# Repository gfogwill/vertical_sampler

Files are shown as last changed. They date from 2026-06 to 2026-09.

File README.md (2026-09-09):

# Vertical Sampler

Firmware, hardware and host software for a balloon-borne vertical air sampler for Ice Nucleating Particle (INP) collection.

Payload and ground-station Raspberry Pi Pico W boards run **CircuitPython** and communicate over **LoRa at 868 MHz**. The system supports two payload identities: `kenttarova` and `matorova`.

## System Overview

```text
┌─────────────────────────┐        LoRa 868 MHz         ┌─────────────────────────┐
│        PAYLOAD          │◄───────────────────────────►│    GROUND STATION       │
│  Raspberry Pi Pico W    │                             │  Raspberry Pi Pico W    │
│                         │                             │                         │
│  - GPS (+ RTC sync)     │                             │  - Receives telemetry   │
│  - SHT85 RH/temp sensor │                             │  - Relays to PC via USB │
│  - LPS25H pressure      │                             │  - Forwards commands    │
│  - Pumps + electrovalve │                             └─────────────────────────┘
│  - SD logging           │                                         │
│  - Battery + flow meter │                                    USB Serial
│  - Watchdog             │                                         │
└─────────────────────────┘                             ┌─────────────────────────┐
                                                        │       Host computer     │
                                                        │ host/cli.py             │
                                                        │ host/quickview.py       │
                                                        └─────────────────────────┘
```

## Repository Structure

```text
vertical_sampler/
├── firmware/                    # CircuitPython code deployed to Pico boards
│   ├── common/                  # Copied flat to every CIRCUITPY drive
│   │   ├── config.py            # PCB v1 GPIOs, calibration, limits, LoRa addresses
│   │   ├── payload.py           # Active payload drivers and mission loop
│   │   ├── lora.py              # RFM9x wrapper
│   │   ├── pressure_sensor.py   # LPS25H driver
│   │   ├── sdcard.py            # SD mount, JSONL data and log writes
│   │   ├── logging.py
│   │   ├── pack.py              # Binary LoRa telemetry format
│   │   ├── led.py
│   │   ├── adafruit_gps.py      # Vendored CircuitPython dependency
│   │   └── adafruit_rfm9x.py    # Vendored CircuitPython dependency
│   ├── kenttarova_main.py       # kenttarova payload entry point
│   ├── matorova_main.py         # matorova payload entry point
│   └── ground_main.py           # Ground-station entry point
├── host/                        # Python 3 programs running on the control PC
│   ├── cli.py
│   └── quickview.py
├── pcb/                         # KiCad PCB v1 project
├── docs/
│   └── TROUBLESHOOTING.md
├── Makefile
└── README.md
```

`firmware/common/` is copied as flat modules to the root of `CIRCUITPY`. CircuitPython imports therefore remain simple:

```python
import config
import lora
import pack
```

## Payload Identities

| Unit | LoRa node address | Entry point |
|---|---:|---|
| Ground station | `0x47` | `firmware/ground_main.py` |
| kenttarova | `0x71` | `firmware/kenttarova_main.py` |
| matorova | `0x93` | `firmware/matorova_main.py` |

Addresses, GPIO assignments, calibration constants and safety limits are defined centrally in `firmware/common/config.py`.

## Quick Start

### 1. Flash CircuitPython

```bash
make download-circuitpython-image
```

Copy the resulting `.uf2` to the Pico W while it is in BOOTSEL mode.

### 2. Install dependencies

The repository vendors `adafruit_gps.py` and `adafruit_rfm9x.py`. Install the remaining required CircuitPython libraries in the Pico `lib/` directory, including the dependencies required by the RFM9x driver such as `adafruit_bus_device`.

### 3. Deploy firmware

Set the CircuitPython mount point if needed:

```bash
export CIRCUITPY_PATH=/media/$USER/CIRCUITPY
```

Deploy the required device image:

```bash
make update-kenttarova
make update-matorova
make update-ground
```

Each target:

1. Removes stale `code.py`.
2. Copies all `firmware/common/*.py` modules to the Pico.
3. Copies the selected entry point as `main.py`.

### 4. Control a payload

Run commands from the host computer:

```bash
python host/cli.py kenttarova data
python host/cli.py kenttarova pump front on
python host/cli.py kenttarova pump back off
python host/cli.py kenttarova valve on
python host/cli.py matorova data
```

`host/quickview.py` is available for local data inspection and visualization.

The host dashboards automatically use the latest sea-level pressure observation
from FMI station `Kittilä Matorova` (`fmisid=101985`) as QNH. The value is
refreshed every 10 minutes through the public
[FMI WFS API](https://opendata.fmi.fi/wfs). If FMI is unavailable, the last
fresh FMI value is retained and then the manual/default value of 1013.25 hPa
is used. Pass `--qnh VALUE` to select a different fallback, or
`--no-auto-qnh` to disable automatic updates. Logged monitor samples include
`_qnh_hpa`, `_qnh_source` and `_qnh_observation_time` so derived altitude
remains traceable.

## Telemetry Format

Each payload sample is logged as JSONL when an SD card is available and sent over LoRa as a packed binary packet defined in `firmware/common/pack.py`.

| Field | Type | Description |
|---|---|---|
| `msg_type` | str | `telemetry`, `cmd_ack` or `cmd_err` |
| `payload_id` | str | `kenttarova` or `matorova` |
| `rtc_time` | str | RTC timestamp in ISO 8601 format |
| `gps_time` | uint32/null | GPS UTC Unix epoch |
| `gps_latitude` | float/null | Degrees |
| `gps_longitude` | float/null | Degrees |
| `gps_altitude` | float/null | Metres |
| `rh_sensor_humidity` | float | Relative humidity, % |
| `rh_sensor_temperature` | float | Temperature, °C |
| `pressure_sensor_pressure` | float | Pressure, mbar |
| `pressure_sensor_temperature` | float | Temperature, °C |
| `battery_voltage` | float | Calibrated 6S battery voltage |
| `cpu_temperature` | float | Pico internal temperature, °C |
| `flow` | float | Standard L/min |
| `rssi` | int | Last received LoRa RSSI |
| `pump_front_state` | int | 0 or 1 |
| `pump_back_state` | int | 0 or 1 |
| `valve_state` | int | 0 or 1 |

> **RTC synchronization:** on the first valid GPS fix, the payload sets the onboard RTC to GPS UTC. Subsequent `rtc_time` values remain valid even if the GPS temporarily loses its fix.

## SD Logging

The SD-card handler writes:

| File | Content |
|---|---|
| `/sd/<payload_id>_log.txt` | Human-readable events and diagnostics |
| `/sd/<payload_id>_NNN.jsonl` | One JSON object per sample cycle |

If the SD card is unavailable or fails while operating, the payload continues running and transmitting telemetry over LoRa. Logging degrades to the serial console instead of stopping the mission.

## Safety Features

| Condition | Threshold | Action |
|---|---:|---|
| Battery warning | ≤ 19.8 V | Warning logged |
| Battery critical | ≤ 18.6 V | Pumps off, valve off, error logged |
| CPU temperature warning | ≥ 45 °C | Warning logged |
| CPU temperature critical | ≥ 55 °C | Pumps off, valve off, error logged |
| Main-loop stall | 30 s watchdog timeout | Pico reset |

The watchdog is fed in the main loop, GPS wait loop, LoRa receive loop and failure-report loops.

## PCB v1 Pin Map

| Function | Pico GPIO |
|---|---:|
| GPS UART TX/RX | GP0 / GP1 |
| I2C SDA/SCL | GP2 / GP3 |
| Pump front | GP6 |
| Electrovalve | GP7 |
| SD chip select | GP9 |
| SPI SCK/MOSI/MISO | GP10 / GP11 / GP12 |
| LoRa chip select | GP16 |
| OPC chip select (reserved) | GP17 |
| Pump back | GP21 |
| Battery monitor ADC | GP27 |
| Flowmeter ADC | GP28 |

The RFM9x reset line is not routed on PCB v1. `config.LORA_RESET_DUMMY` remains because the CircuitPython RFM9x driver requires a reset-pin argument.

## Calibration

### Flowmeter

The TSI 4121 flowmeter is configured as:

- Signal range: 0–4 V corresponding to 0–20 Std L/min.
- ADC divider: 10 kΩ series resistor and 32.6 kΩ to ground.
- Divider ratio: \(32.6 / (10.0 + 32.6)\).
- Zero offset: `FLOW_OFFSET_LMIN` in `firmware/common/config.py`.

### Battery monitor

`BATTERY_CAL_FACTOR` in `firmware/common/config.py` converts the Pico ADC voltage to the measured 6S battery voltage. Recalibrate against a multimeter if the divider or analog front-end changes.

## Development Notes

- `firmware/common/payload.py` contains the active, hardware-validated payload drivers and mission loop.
- `firmware/common/config.py` is the single source of truth for PCB pins, calibration, operating limits and LoRa addresses.
- The old breadboard firmware is preserved in the `old_hardware` branch.
- See `docs/TROUBLESHOOTING.md` for deployment and communication diagnostics.

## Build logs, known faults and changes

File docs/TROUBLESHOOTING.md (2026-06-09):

# Troubleshooting

## SD Card not mounting at boot

**Symptom:** `os.listdir("/sd")` raises `OSError: [Errno 2] No such file/directory` after reset, but works fine when `SDCard(spi, ...)` is called manually in the REPL.

**Cause:** `SDCard(...)` is not being called during the boot sequence — either `main()` is not running, or an exception is thrown before the SD mount.

**Fix:** Ensure `main.py` calls `SDCard(spi, fname="log.txt")` at the start of `main()`, before creating the logger. Verify:
```python
import os
print(os.listdir("/"))   # should include 'sd'
print(os.listdir("/sd")) # should include 'log.txt'
```

---

## Payload keeps resetting / autoreload loop

**Symptom:** The payload restarts every time a file is saved to `CIRCUITPY`, or seems to restart randomly during development.

**Cause:** CircuitPython's autoreload is enabled by default. Saving any file to the drive triggers a soft reset.

**Fix:** Add this at the very top of `main.py`, **before any other imports**:
```python
import supervisor
supervisor.runtime.autoreload = False
```

---

## LoRa not initializing / SPI conflict

**Symptom:** `LoRa(...)` raises an exception, or the payload hangs on LoRa init.

**Cause:** LoRa and the SD card share the same SPI bus (GP2/GP3/GP4). SPI bus contention can occur if initialization order is wrong.

**Fix:** Always initialize `SDCard` before `LoRa` in `main()`.

---

## GPS not acquiring fix

**Symptom:** Logger shows `Waiting for GPS fix...` repeatedly.

**Fix:**
- Allow more time outdoors with a clear sky view (cold start can take 1–2 minutes).
- Increase `max_attempts` and `timeout` in `GPS.lat_lon_alt_time()`.
- Check UART wiring (GP0/GP1) and baud rate (9600).

---

## `log.txt` grows indefinitely

**Behavior (expected):** `log.txt` uses append mode and accumulates across all boots. This is intentional for flight data recovery.

**To clear the log:**
```python
import os
os.remove("/sd/log.txt")
```

---

## Payload boots but `/sd` does not appear

**Verify** the SD card is physically inserted and CS pin is GP18.

**Test manually in REPL:**
```python
import board, busio
from sdcard import SDCard
spi = busio.SPI(board.GP2, MOSI=board.GP3, MISO=board.GP4)
sd = SDCard(spi, "log.txt")
import os
print(os.listdir("/sd"))
```
If this works but boot does not, the problem is in `main.py` initialization order.

---

## `cli.py` can't find the serial port

**Fix:** Make sure the ground station Pico W is connected via USB. On Linux:
```bash
sudo usermod -a -G dialout $USER
# then log out and back in
```

---

## `cp: error writing ... No space left on device` after flashing UF2

**Symptom:** `make update-*` fails with:
```
cp: error writing '/media/.../CIRCUITPY/adafruit_gps.py': No space left on device
```
This happens even immediately after flashing a fresh UF2.

**Cause:** CircuitPython's `CIRCUITPY` drive has a fixed filesystem size baked into the UF2. By default it is **~1 MB**, which fills up quickly with libraries. Flashing the UF2 again does **not** wipe or resize the filesystem — it only replaces the firmware, leaving the old filesystem intact.

**Fix — wipe and resize the filesystem:**

1. **Enter bootloader mode:** hold BOOTSEL while plugging in USB (or double-tap RESET). The drive `RPI-RP2` appears.

2. **Flash the CircuitPython UF2** (if not already done): drag the `.uf2` onto `RPI-RP2`.

3. **Wipe the filesystem from the REPL.** Connect via serial (Thonny or `screen /dev/ttyACM0 115200`) and run:
   ```python
   import storage
   storage.erase_filesystem()
   ```
   The board will reboot and format a **fresh, empty** `CIRCUITPY` filesystem.

4. **Run `make update-*` again.** The drive is now empty and should have enough space.

**Prevention:** If the drive keeps filling up, remove unused `.py` or `.mpy` files. Pre-compiled `.mpy` files (from the Adafruit CircuitPython Bundle) are significantly smaller than `.py` sources — use them for large libraries like `adafruit_gps`.

**Check available space from REPL:**
```python
import os
s = os.statvfs("/")
free_kb = s[0] * s[3] / 1024
print("Free:", free_kb, "KB")
```

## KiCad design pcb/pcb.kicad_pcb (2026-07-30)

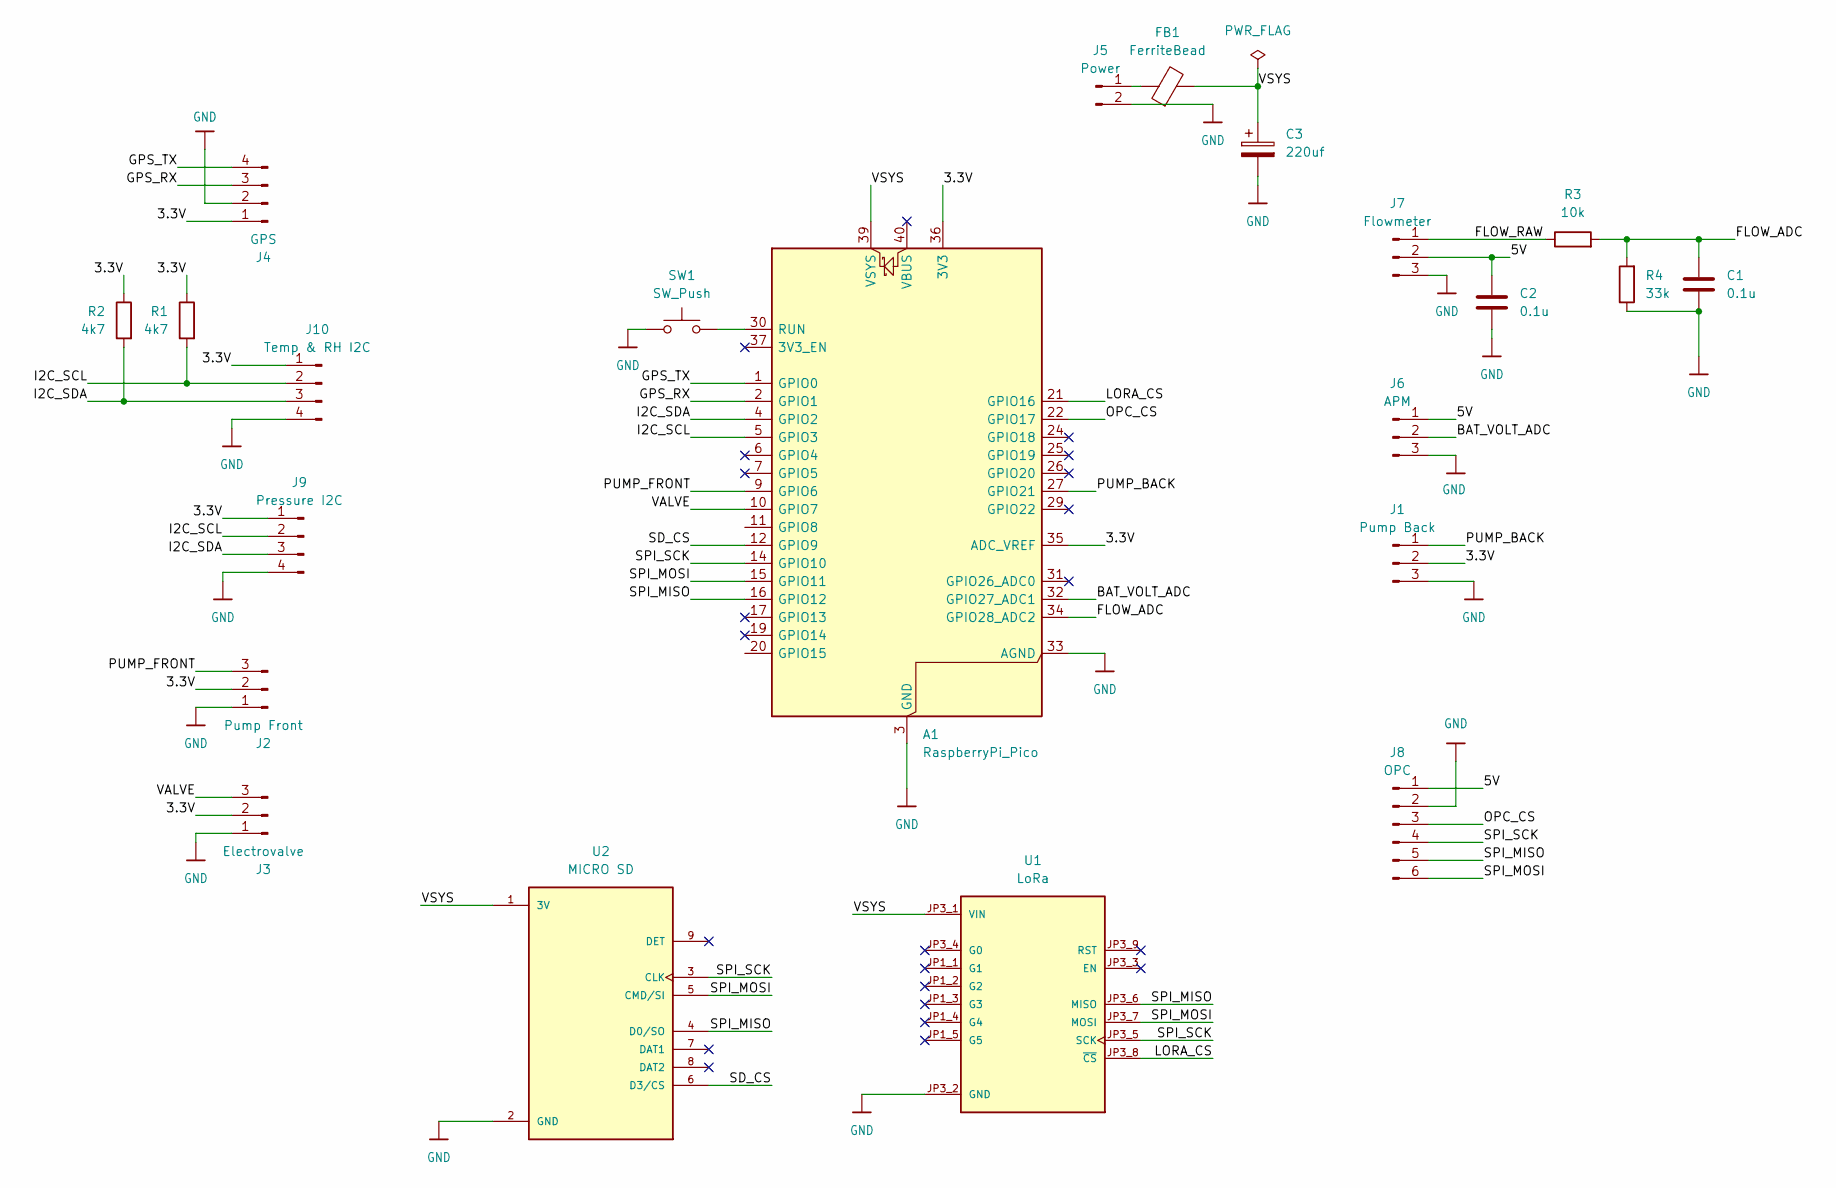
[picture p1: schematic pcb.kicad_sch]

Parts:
A1: RaspberryPi_Pico; RaspberryPi_Pico_Common_THT
C1, C2: 0.1u; C_1206_3216Metric
C3: 220uf; CP_Radial_D6.3mm_P2.50mm
FB1: FerriteBead; L_1206_3216Metric
J1: Pump Back; JST_XH_B3B-XH-A_1x03_P2.50mm_Vertical
J2: Pump Front; JST_XH_B3B-XH-A_1x03_P2.50mm_Vertical
J3: Electrovalve; JST_XH_B3B-XH-A_1x03_P2.50mm_Vertical
J4: GPS; JST_XH_B4B-XH-A_1x04_P2.50mm_Vertical
J5: Power; JST_XH_B2B-XH-A_1x02_P2.50mm_Vertical
J6: APM; JST_XH_B3B-XH-A_1x03_P2.50mm_Vertical
J7: Flowmeter; JST_XH_B3B-XH-A_1x03_P2.50mm_Vertical
J8: OPC; JST_XH_B6B-XH-A_1x06_P2.50mm_Vertical
J9: Pressure I2C; JST_XH_B4B-XH-A_1x04_P2.50mm_Vertical
J10: Temp & RH I2C; JST_XH_B4B-XH-A_1x04_P2.50mm_Vertical
R1, R2: 4k7; R_1206_3216Metric
R3: 10k; R_1206_3216Metric
R4: 33k; R_1206_3216Metric
SW1: SW_Push; SW_PUSH_6mm
U1: LoRa; MODULE_3073; PARTREV 2023-10-24
U2: MICRO SD; MODULE_MICROSD_SPI_OR_SDIO_CARD; PARTREV B

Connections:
/3.3V: A1.35 (ADC_VREF), A1.36 (3V3), J1.2, J2.2, J3.2, J4.1, J9.1, J10.1, R1.1, R2.1
/5V: C2.1, J6.1, J7.2, J8.1
/BAT_VOLT_ADC: A1.32 (GPIO27_ADC1), J6.2
/FLOW_ADC: A1.34 (GPIO28_ADC2), C1.1, R3.2, R4.2
/FLOW_RAW: J7.1, R3.1
/GPS_RX: A1.2 (GPIO1), J4.3
/GPS_TX: A1.1 (GPIO0), J4.4
/I2C_SCL: A1.5 (GPIO3), J9.2, J10.2, R1.2
/I2C_SDA: A1.4 (GPIO2), J9.3, J10.3, R2.2
/LORA_CS: A1.21 (GPIO16), U1.JP3_8 (~CS)
/OPC_CS: A1.22 (GPIO17), J8.3
/PUMP_BACK: A1.27 (GPIO21), J1.1
/PUMP_FRONT: A1.9 (GPIO6), J2.3
/SD_CS: A1.12 (GPIO9), U2.6 (D3/CS)
/SPI_MISO: A1.16 (GPIO12), J8.5, U1.JP3_6 (MISO), U2.4 (D0/SO)
/SPI_MOSI: A1.15 (GPIO11), J8.6, U1.JP3_7 (MOSI), U2.5 (CMD/SI)
/SPI_SCK: A1.14 (GPIO10), J8.4, U1.JP3_5 (SCK), U2.3 (CLK)
/VALVE: A1.10 (GPIO7), J3.3
/VSYS: A1.39 (VSYS), C3.1, FB1.2, U1.JP3_1 (VIN), U2.1 (3V)
GND: A1.3 (GND), A1.8 (GND), A1.13 (GND), A1.18 (GND), A1.23 (GND), A1.28 (GND), A1.33 (AGND), A1.38 (GND), C1.2, C2.2, C3.2, J1.3, J2.1, J3.1, J4.2, J5.2, J6.3, J7.3, J8.2, J9.4, J10.4, R4.1, SW1.1, U1.JP3_2 (GND), U2.2 (GND)
unnamed: A1.30 (RUN), SW1.2
unnamed: FB1.1, J5.1

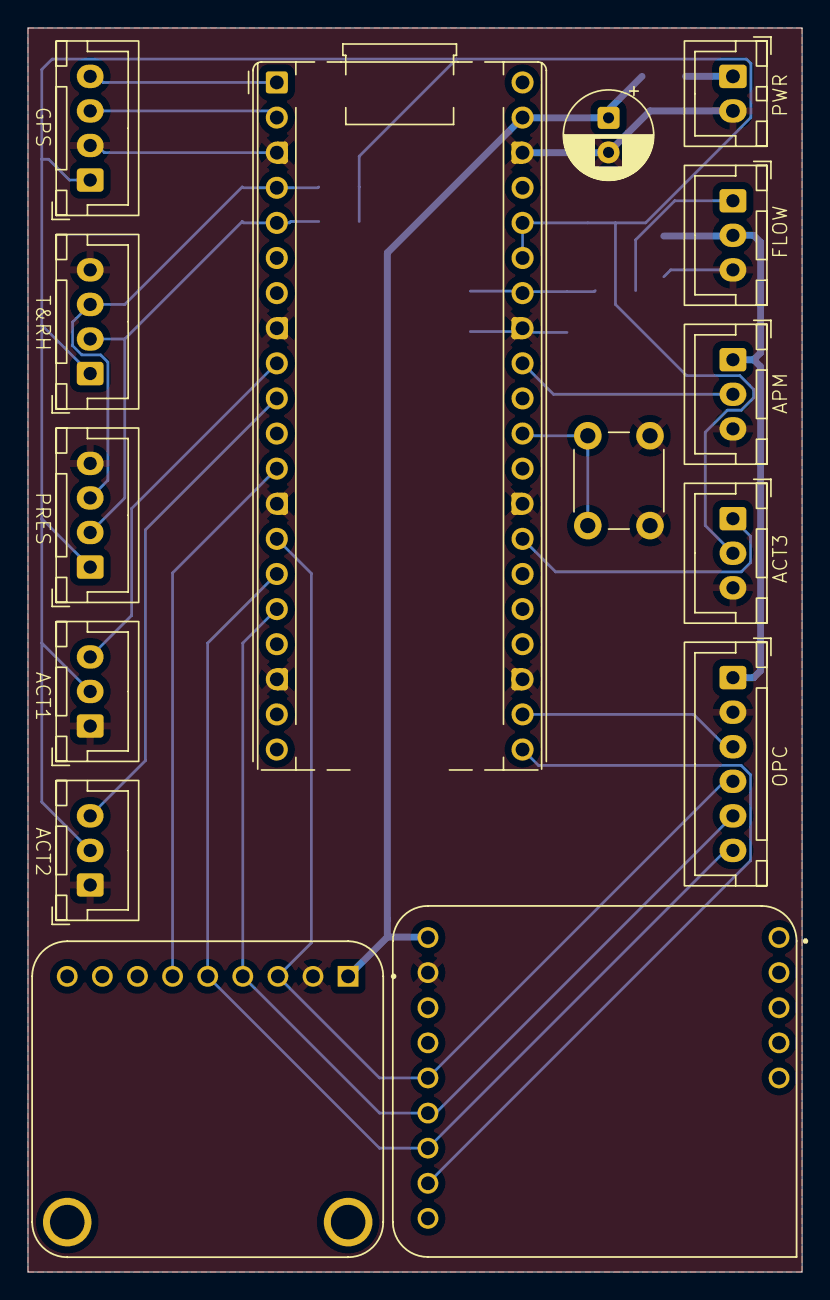
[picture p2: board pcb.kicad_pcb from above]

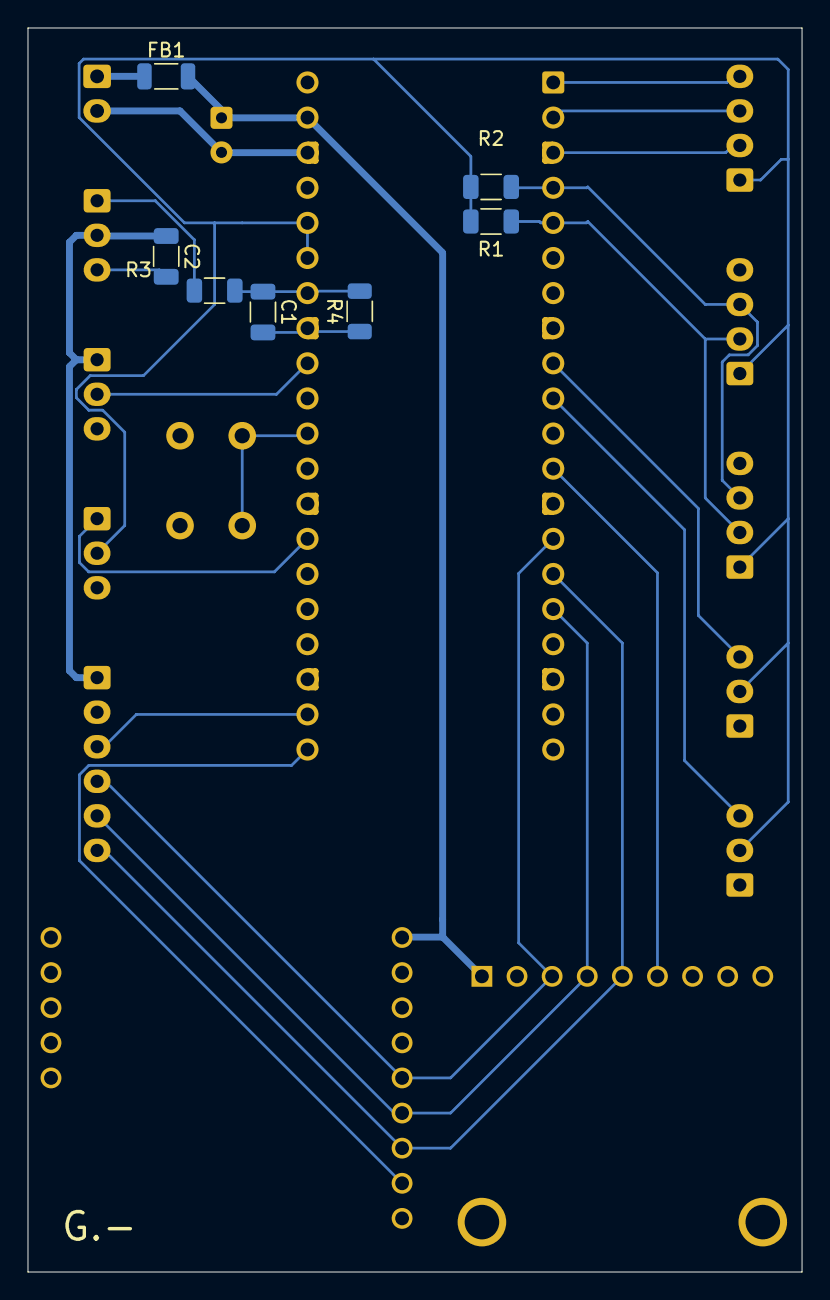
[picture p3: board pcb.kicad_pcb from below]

Board: 2 copper layers, 56.0 x 90.0 mm, 22 parts (7 on the bottom side), 22 nets.

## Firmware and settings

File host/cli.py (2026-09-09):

import argparse
import json
import math
import queue
import threading
import time
from enum import Enum
import datetime
import struct

import serial

if __package__:
    from .fmi_qnh import DEFAULT_QNH_HPA, QnhProvider
else:
    from fmi_qnh import DEFAULT_QNH_HPA, QnhProvider


class Payload(Enum):
    MATOROVA = "matorova"
    KENTTAROVA = "kenttarova"

    def __str__(self) -> str:
        return self.value


class State(Enum):
    ON = "on"
    OFF = "off"

    def __str__(self) -> str:
        return self.value


FILL_INT = -999999
FILL_UINT = 4294967295
FILL_FLOAT = -1e9

PAYLOAD_CYCLE_S = 35
RETRY_INTERVAL_S = 5
MAX_RETRIES = int(PAYLOAD_CYCLE_S / RETRY_INTERVAL_S) + 1
# An actuator command is sent once because a missing ACK does not tell us
# whether the payload applied the command.  This covers ground-side LoRa wait.
ACTUATOR_RESPONSE_TIMEOUT_S = 25

# Wire format constants (must match payload/pack.py)
_MSG_TYPE_LEN = 12  # field is 12s in struct format
_MSG_TELEMETRY = "telemetry"
_MSG_CMD_ACK = "cmd_ack"
_MSG_CMD_ERR = "cmd_err"
_CMD_RESPONSE_TYPES = {_MSG_CMD_ACK, _MSG_CMD_ERR}

_UTC = datetime.timezone.utc

FIELDS = [
    ("gps_latitude",                "Latitude",          "\u00b0",    "GPS"),
    ("gps_longitude",               "Longitude",         "\u00b0",    "GPS"),
    ("gps_altitude",                "Altitude (GPS)",    "m",     "GPS"),
    ("gps_time",                    "Time (GPS)",        "UTC",   "GPS"),
    ("rh_sensor_humidity",          "Humidity",          "%RH",   "Atmosphere"),
    ("rh_sensor_temperature",       "Temperature (RH)",  "\u00b0C",   "Atmosphere"),
    ("pressure_sensor_pressure",    "Pressure",          "hPa",   "Atmosphere"),
    ("pressure_sensor_temperature", "Temperature (P)",   "\u00b0C",   "Atmosphere"),
    ("_pressure_altitude",          "Altitude (P)",      "m",     "Atmosphere"),
    ("flow",                        "Flow",              "L/min", "Sampler"),
    ("pump_front_state",            "Pump front",        "",      "Sampler"),
    ("pump_back_state",             "Pump back",         "",      "Sampler"),
    ("valve_state",                 "Valve",             "",      "Sampler"),
    ("_opc_bin_total",              "Bin total (raw)",   "cnt",   "OPC"),
    ("opc_temperature",             "Temperature",       "\u00b0C",   "OPC"),
    ("opc_humidity",                "Humidity",          "%RH",   "OPC"),
    ("opc_sample_flow",             "Sample flow",       "mL/s",  "OPC"),
    ("opc_laser_status",            "Laser status",      "",      "OPC"),
    ("battery_voltage",             "Battery",           "V",     "System"),
    ("cpu_temperature",             "CPU temp",          "\u00b0C",   "System"),
    ("rssi",                        "RSSI",              "dBm",   "System"),
]

GROUP_ORDER = ["GPS", "Atmosphere", "Sampler", "OPC", "System"]

# Control key map: key -> (payload_index, actuator, label)
# Uppercase = matorova (index 0), lowercase = kenttarova (index 1)
_CTRL_KEYS = {
    ord('F'): (0, "pump", "front"),
    ord('f'): (1, "pump", "front"),
    ord('B'): (0, "pump", "back"),
    ord('b'): (1, "pump", "back"),
    ord('V'): (0, "valve", None),
    ord('v'): (1, "valve", None),
}

# Per-payload additive pressure offsets (hPa) calibrated against TSI 4100 reference
_PRESSURE_OFFSET_HPA = {
    Payload.MATOROVA: +2.1,     # offset = P_TSI_4100 - P_sensor_crudo (medido en calibración)
    Payload.KENTTAROVA: -1.9,
}


def _apply_pressure_offset(payload, pressure_hpa):
    if pressure_hpa is None:
        return None
    offset = _PRESSURE_OFFSET_HPA.get(payload, 0.0)
    return pressure_hpa + offset


def _pressure_altitude(pressure_hpa, qnh_hpa):
    try:
        return 44330.0 * (1.0 - math.pow(pressure_hpa / qnh_hpa, 0.1903))
    except Exception:
        return None


def _fmt_value(key, val):
    if val is None:
        return "N/A", True
    if isinstance(val, float) and abs(val - FILL_FLOAT) < 1:
        return "N/A", True
    if isinstance(val, int) and val in (FILL_INT, FILL_UINT):
        return "N/A", True
    if key == "gps_time":
        try:
            ts = datetime.datetime.fromtimestamp(val, tz=_UTC)
            return ts.strftime("%H:%M:%S"), False
        except Exception:
            return str(val), False
    if key in ("pump_front_state", "pump_back_state"):
        return ("ON" if val else "OFF"), False
    if key == "valve_state":
        return str(val), False
    if isinstance(val, float):
        return "{:.2f}".format(val), False
    return str(val), False


def pretty_print(data, payload_id=""):
    COL_LABEL = 26
    COL_VALUE = 10
    COL_UNIT = 7
    W = COL_LABEL + COL_VALUE + COL_UNIT + 6
    title = " {} ".format(payload_id.upper() if payload_id else "TELEMETRY")
    lines = []
    lines.append("\u2554" + "\u2550" * W + "\u2557")
    lines.append("\u2551" + title.center(W) + "\u2551")
    lines.append("\u2560" + "\u2550" * (COL_LABEL + 2) + "\u2566" + "\u2550" * (COL_VALUE + 2) + "\u2566" + "\u2550" * (COL_UNIT + 2) + "\u2563")
    grouped = {g: [] for g in GROUP_ORDER}
    for key, label, unit, group in FIELDS:
        if key.startswith("_"):
            continue
        grouped[group].append((key, label, unit))
    for g_idx, group in enumerate(GROUP_ORDER):
        group_title = " " + group
        lines.append("\u2551 " + group_title.ljust(COL_LABEL) + " \u2551 " + " " * COL_VALUE + " \u2551 " + " " * COL_UNIT + " \u2551")
        for key, label, unit in grouped[group]:
            val = data.get(key)
            val_str, is_fill = _fmt_value(key, val)
            label_col = " " + label
            if is_fill:
                val_str = "N/A"
                unit = ""
            lines.append(
                "\u2551 " + label_col.ljust(COL_LABEL) +
                " \u2551 " + val_str.rjust(COL_VALUE) +
                " \u2551 " + unit.ljust(COL_UNIT) + " \u2551"
            )
        if g_idx < len(GROUP_ORDER) - 1:
            lines.append("\u2560" + "\u2550" * (COL_LABEL + 2) + "\u256c" + "\u2550" * (COL_VALUE + 2) + "\u256c" + "\u2550" * (COL_UNIT + 2) + "\u2563")
    lines.append("\u255a" + "\u2550" * (COL_LABEL + 2) + "\u2569" + "\u2550" * (COL_VALUE + 2) + "\u2569" + "\u2550" * (COL_UNIT + 2) + "\u255d")
    print("\n" + "\n".join(lines) + "\n")


def find_serial(baudrate=9600, timeout=2):
    import serial.tools.list_ports
    ports = list(serial.tools.list_ports.comports())
    for port in ports:
        if "Pico" in (port.description or "") or "CircuitPython" in (port.description or ""):
            return serial.Serial(port.device, baudrate=baudrate, timeout=timeout)
    if ports:
        return serial.Serial(ports[0].device, baudrate=baudrate, timeout=timeout)
    raise RuntimeError("No serial port found. Is the ground station Pico connected?")


def _build_cmd(args):
    if args.subcommand == "pump":
        return "{} {} {} {}\n".format(args.payload, args.subcommand, args.pump_location, args.state).encode()
    elif args.subcommand == "valve":
        return "{} {} {}\n".format(args.payload, args.subcommand, args.state).encode()
    elif args.subcommand == "data":
        return "{} {}\n".format(args.payload, args.subcommand).encode()
    else:
        raise ValueError("Unknown subcommand: {}".format(args.subcommand))


def _read_json_line(ser, timeout_s):
    deadline = time.time() + timeout_s
    while time.time() < deadline:
        if ser.in_waiting:
            raw = ser.readline()
            text = raw.decode(errors="ignore").strip()
            if not text:
                continue
            if text.startswith("{") or text.startswith("["):
                try:
                    return json.loads(text)
                except json.JSONDecodeError:
                    pass
        else:
            time.sleep(0.05)
    return None


def _drain_serial(ser, timeout_s=0.5):
    """Discard stale bytes/lines already in the serial buffer."""
    deadline = time.time() + timeout_s
    while time.time() < deadline:
        if ser.in_waiting:
            ser.readline()  # discard
        else:
            time.sleep(0.05)


def _read_cmd_response(ser, timeout_s, accept_telemetry=False, expected_payload=None):
    """Read lines until we get a suitable response packet.

    If accept_telemetry=True (used for the 'data' command), a
    msg_type='telemetry' packet is also accepted as a valid response.
    If accept_telemetry=False (default), only cmd_ack and cmd_err are
    accepted; heartbeats are skipped so they cannot be mistaken for a
    command acknowledgement.
    """
    deadline = time.time() + timeout_s
    while time.time() < deadline:
        if ser.in_waiting:
            raw = ser.readline()
            if not raw or raw == b"\x00" * len(raw):
                continue
            text = raw.decode(errors="ignore").strip()
            if not text:
                continue
            if text.startswith("{"):
                try:
                    d = json.loads(text)
                    msg_type = d.get("msg_type", _MSG_TELEMETRY)
                    if (
                        expected_payload is not None
                        and d.get("payload_id") != str(expected_payload)
                    ):
                        continue
                    if msg_type in _CMD_RESPONSE_TYPES:
                        return d
                    if accept_telemetry and msg_type == _MSG_TELEMETRY:
                        return d
                except json.JSONDecodeError:
                    pass
        else:
            time.sleep(0.05)
    return None


def _opc_bin_total(d):
    """Sum raw OPC-N3 bin counts (opc_bin_0..opc_bin_23) if present and not fill values."""
    total = 0
    found = False
    for i in range(24):
        v = d.get("opc_bin_{}".format(i))
        if v is None or (isinstance(v, int) and v == FILL_UINT):
            continue
        total += v
        found = True
    return total if found else None


def _enrich_data(data, payload, qnh_hpa=DEFAULT_QNH_HPA):
    """Apply pressure offset, compute pressure altitude and OPC bin total in-place."""
    p = data.get("pressure_sensor_pressure")
    if p is not None and isinstance(p, (int, float)) and abs(p - FILL_FLOAT) > 1:
        p_corrected = _apply_pressure_offset(payload, p)
        data["pressure_sensor_pressure"] = p_corrected
        data["_pressure_altitude"] = _pressure_altitude(p_corrected, qnh_hpa)
    else:
        data["_pressure_altitude"] = None
    data["_opc_bin_total"] = _opc_bin_total(data)
    return data


def _known_binary_state(data, key):
    value = data.get(key)
    return value if value in (0, 1) else None


def relay_cmd(args):
    cmd = _build_cmd(args)
    is_data = (args.subcommand == "data")
    max_attempts = MAX_RETRIES if is_data else 1
    response_timeout_s = RETRY_INTERVAL_S if is_data else ACTUATOR_RESPONSE_TIMEOUT_S
    with find_serial() as ser:
        time.sleep(0.2)
        _drain_serial(ser, timeout_s=0.5)
        for attempt in range(1, max_attempts + 1):
            print("Sending command (attempt {}/{})...".format(attempt, max_attempts), end="", flush=True)
            ser.write(cmd)
            ser.flush()
            data = _read_cmd_response(
                ser,
                timeout_s=response_timeout_s,
                accept_telemetry=is_data,
                expected_payload=args.payload,
            )
            if data is not None:
                print(" OK" if data.get("msg_type") != _MSG_CMD_ERR else " ERROR")
                if args.subcommand == "data":
                    _enrich_data(data, args.payload)
                    pretty_print(data, payload_id=str(args.payload))
                else:
                    print(json.dumps(data, indent=2))
                return
            if not is_data:
                print(" no response; command may have been applied, not retrying.")
                break
            print(" no response, retrying...")
        if is_data:
            print("ERROR: no response from {} after {} attempts (~{}s).".format(
                args.payload, max_attempts, max_attempts * response_timeout_s
            ))
        else:
            print("ERROR: no command acknowledgement from {}; actuator state is unknown.".format(
                args.payload
            ))


# ---------------------------------------------------------------------------
# Monitor TUI
# ---------------------------------------------------------------------------

MAX_EVENTS = 8
_PAYLOADS_ALL = [Payload.MATOROVA, Payload.KENTTAROVA]

_CMD_POLL_ALL = "poll_all"
_CMD_POLL_ONE = "poll_one"
_CMD_CONTROL = "control"
_CMD_QUIT = "quit"


class PollWorker(threading.Thread):
    def __init__(self, payloads, qnh_provider, log_file):
        super().__init__(daemon=True)
        self.payloads = payloads
        self.qnh_provider = qnh_provider
        self.log_file = log_file
        self.cmd_q = queue.Queue()
        self.result_q = queue.Queue()

    def _enrich(self, d, payload):
        qnh_state = self.qnh_provider.snapshot()
        p = d.get("pressure_sensor_pressure")
        if p is not None and isinstance(p, (int, float)) and abs(p - FILL_FLOAT) > 1:
            p_corrected = _apply_pressure_offset(payload, p)
            d["pressure_sensor_pressure_corrected"] = p_corrected
            d["_pressure_altitude"] = _pressure_altitude(p_corrected, qnh_state.qnh_hpa)
        else:
            d["pressure_sensor_pressure_corrected"] = None
            d["_pressure_altitude"] = None
        d["_qnh_hpa"] = qnh_state.qnh_hpa
        d["_qnh_source"] = qnh_state.source
        if qnh_state.observation_time is not None:
            d["_qnh_observation_time"] = qnh_state.observation_time.isoformat()
        d["_opc_bin_total"] = _opc_bin_total(d)
        return d

    def _log(self, d):
        if self.log_file:
            try:
                with open(self.log_file, "a") as f:
                    f.write(json.dumps(d) + "\n")
            except Exception:
                pass

    def _poll_one(self, ser, payload):
        cmd = "{} data\n".format(payload).encode()
        _drain_serial(ser, timeout_s=0.5)
        ser.write(cmd)
        ser.flush()
        d = _read_cmd_response(
            ser,
            timeout_s=6,
            accept_telemetry=True,
            expected_payload=payload,
        )
        if d is not None:
            d["_ts"] = time.time()
            self._enrich(d, payload)
            self._log(d)
            self.result_q.put((payload, d))

    def _send_control(self, ser, cmd_bytes, payload):
        _drain_serial(ser, timeout_s=0.5)
        ser.write(cmd_bytes)
        ser.flush()
        d = _read_cmd_response(
            ser,
            timeout_s=ACTUATOR_RESPONSE_TIMEOUT_S,
            expected_payload=payload,
        )
        if d is not None:
            d["_ts"] = time.time()
            self._enrich(d, payload)
            self._log(d)
        return d

    def _try_parse_heartbeat(self, ser):
        if ser.in_waiting:
            raw = ser.readline()
            if not raw or raw == b"\x00" * len(raw):
                return
            text = raw.decode(errors="ignore").strip()
            if text.startswith("{"):
                try:
                    d = json.loads(text)
                    msg_type = d.get("msg_type", _MSG_TELEMETRY)
                    if msg_type not in (_MSG_TELEMETRY, ""):
                        return
                    d["_ts"] = time.time()
                    # Heartbeats may omit a payload id; pass None so offset defaults to 0.0
                    self._enrich(d, None)
                    self._log(d)
                    self.result_q.put((None, d))
                except Exception:
                    pass

    def run(self):
        try:
            ser = find_serial(baudrate=9600, timeout=0.5)
        except Exception as e:
            self.result_q.put((None, {"_error": str(e)}))
            return

        with ser:
            time.sleep(0.2)
            ser.reset_input_buffer()

            while True:
                try:
                    item = self.cmd_q.get_nowait()
                    if item == _CMD_QUIT:
                        break
                    elif item == _CMD_POLL_ALL:
                        for p in self.payloads:
                            self._poll_one(ser, p)
                    elif isinstance(item, tuple) and item[0] == _CMD_POLL_ONE:
                        self._poll_one(ser, item[1])
                    elif isinstance(item, tuple) and item[0] == _CMD_CONTROL:
                        _, payload, cmd_bytes = item
                        d = self._send_control(ser, cmd_bytes, payload)
                        self.result_q.put((payload, d))
                        continue
                except queue.Empty:
                    pass

                self._try_parse_heartbeat(ser)
                time.sleep(0.05)


def _safe_addnstr(win, row, col, text, max_cols, attr):
    import curses
    rows, cols = win.getmaxyx()
    if row < 0 or row >= rows - 1:
        return
    if col < 0 or col >= cols - 1:
        return
    avail = min(max_cols, cols - col - 1)
    if avail <= 0:
        return
    try:
        win.addnstr(row, col, text, avail, attr)
    except curses.error:
        pass


def _render_column(win, data, payload_label, col_x, col_w, max_rows):
    import curses
    row = 1
    header = " {} ".format(payload_label.upper())
    _safe_addnstr(win, row, col_x, header.center(col_w), col_w,
                  curses.color_pair(2) | curses.A_BOLD)
    row += 1
    if not data:
        _safe_addnstr(win, row, col_x, " --- no data ---".ljust(col_w), col_w,
                      curses.color_pair(3))
        return
    last_updated = data.get("_ts")
    if last_updated:
        age = int(time.time() - last_updated)
        ts_str = " updated {}s ago".format(age)
    else:
        ts_str = ""
    _safe_addnstr(win, row, col_x, ts_str.ljust(col_w), col_w, curses.color_pair(4))
    row += 1
    grouped = {g: [] for g in GROUP_ORDER}
    for key, label, unit, group in FIELDS:
        grouped[group].append((key, label, unit))
    for group in GROUP_ORDER:
        if row >= max_rows:
            break
        _safe_addnstr(win, row, col_x, " {}".format(group).ljust(col_w), col_w,
                      curses.color_pair(2) | curses.A_UNDERLINE)
        row += 1
        for key, label, unit in grouped[group]:
            if row >= max_rows:
                break
            val = data.get(key)
            val_str, is_fill = _fmt_value(key, val)
            if key in ("pump_front_state", "pump_back_state") and val:
                attr = curses.color_pair(4) | curses.A_BOLD
            elif key == "valve_state" and val:
                attr = curses.color_pair(4) | curses.A_BOLD
            elif is_fill:
                attr = curses.color_pair(3)
            else:
                attr = curses.color_pair(1)
            line = " {:<18} {:>8} {}".format(label, val_str, unit)
            _safe_addnstr(win, row, col_x, line.ljust(col_w), col_w, attr)
            row += 1
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

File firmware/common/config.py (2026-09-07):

"""Pin assignment and operating constants for PCB v1.

This is the single source of truth for firmware GPIO assignments.
"""

import board

GPS_UART_TX = board.GP0
GPS_UART_RX = board.GP1
I2C_SDA = board.GP2
I2C_SCL = board.GP3
PUMP_FRONT = board.GP6
ELECTROVALVE = board.GP7
SD_CS = board.GP9
SPI_SCK = board.GP10
SPI_MOSI = board.GP11
SPI_MISO = board.GP12
LORA_CS = board.GP16
OPC_CS = board.GP17
PUMP_BACK = board.GP21
BATTERY_MONITOR = board.GP27
FLOWMETER = board.GP28

# RFM9x RST is not routed on PCB v1. This unconnected pin is retained only
# because the CircuitPython driver requires a DigitalInOut reset argument.
LORA_RESET_DUMMY = board.GP14

# LoRa node addresses
GROUND_RFM_ADDRESS = 0x47
KENTTAROVA_RFM_ADDRESS = 0x71
MATOROVA_RFM_ADDRESS = 0x93

FLOW_DIVIDER_RATIO = 32.6 / (10.0 + 32.6)
FLOW_FULL_SCALE_V = 4.0
FLOW_FULL_SCALE_LMIN = 20.0
FLOW_OFFSET_LMIN = 0.25
BATTERY_CAL_FACTOR = 10.15
BATTERY_WARN_V = 19.8
BATTERY_CUTOFF_V = 18.6
CPU_TEMP_WARN_C = 45.0
CPU_TEMP_CRITICAL_C = 55.0
WATCHDOG_TIMEOUT_S = 30
HEARTBEAT_INTERVAL_S = 60
HEARTBEAT_OFFSETS = {
    "matorova": 0,
    "kenttarova": 30,
}

# Log levels persisted to SD. INFO/DEBUG are printed to console only, to
# minimize SD write activity during normal operation. DATA always persists
# via Logger.data(), independent of this list.
SD_LOG_LEVELS = ("WARNING", "ERROR")

# Delay at the very start of main(), before any peripheral is touched.
# The OPC-N3 has its own internal MCU that needs time to complete its own
# boot sequence after power-up; probing it over SPI too early can leave it
# in a state that only a physical reset recovers from.
STARTUP_DELAY_S = 2.0

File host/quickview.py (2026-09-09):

#!/usr/bin/env python3
"""
QuickView: live ground control dashboard for JSONL backups written by cli.py --log-file.

Usage:
python host/quickview.py --log-file ground_dump.jsonl
python host/quickview.py -f ground_dump.jsonl --qnh 1015.7 --max-points 600

Supported JSON line formats:
- {"pc_time": "...", "payload": "matorova", "data": {...}} (wrapped)
- {...} with "payload_id" inside (flat, cli.py format)

Panels (top to bottom, shared local-time X axis):
0. Battery (V) -> with warning/cutoff reference lines
1. Temperatures (C) -> CPU / pressure sensor / RH, per payload
2. Pressure (hPa)
3. Altitude (m) -> GPS (solid) vs pressure-derived via QNH (dashed)
4. Relative humidity (%)
5. Flow (L/min, left axis) + cumulative sampled volume (L, right axis)
6. OPC-N3 size-distribution heatmap (kenttarova only): time x bin (0-23), raw counts
7. OPC-N3 scalars (kenttarova only): temperature / humidity / sample flow + laser status
"""

import argparse
import json
from collections import defaultdict, deque
from datetime import datetime, timezone, timedelta

import matplotlib.pyplot as plt
import matplotlib.animation as animation
import matplotlib.dates as mdates
import matplotlib.gridspec as gridspec
from matplotlib.lines import Line2D

if __package__:
    from .fmi_qnh import DEFAULT_QNH_HPA, QnhProvider, is_valid_qnh
else:
    from fmi_qnh import DEFAULT_QNH_HPA, QnhProvider, is_valid_qnh

# ---------------------------------------------------------------------------
# General configuration
# ---------------------------------------------------------------------------
PAYLOADS = ["matorova", "kenttarova"]

# "Flight instrument" palette: cyan and amber on near-black background
PAYLOAD_COLORS = {
    "matorova": "#39C8E8",    # cyan
    "kenttarova": "#F5A623",  # amber
}

BAT_WARN_V = 19.8
BAT_CUTOFF_V = 18.6
TEMP_WARN_C = 45.0
TEMP_CRITICAL_C = 55.0

MIN_VALID_YEAR = 2024        # minimum year to trust rtc_time (factory default is 2020)
MAX_ANCHOR_GAP_S = 6 * 3600  # discard reconstructed timestamps drifting further than this

FILL_UINT = 4294967295
FILL_INT = -999999


def parse_args():
    p = argparse.ArgumentParser(description="QuickView: live ground control terminal for vertical_sampler")
    p.add_argument("--log-file", "-f", default="ground_dump.jsonl",
                   help="JSONL file written by cli.py --log-file")
    p.add_argument("--max-points", type=int, default=0,
                   help="Max points per payload kept in memory (0 = unlimited, full history)")
    p.add_argument("--interval-ms", type=int, default=1000,
                   help="Refresh interval (ms)")
    p.add_argument(
        "--qnh",
        type=float,
        default=None,
        help="Manual QNH fallback (hPa); FMI Kittilä Matorova is used by default",
    )
    p.add_argument("--no-auto-qnh", action="store_true",
                   help="Disable automatic FMI QNH updates")
    p.add_argument("--theme", choices=["dark", "light"], default="dark",
                   help="Dashboard visual theme")
    p.add_argument("--stale-after", type=float, default=90.0,
                   help="Seconds without data before a payload/actuator is marked stale")
    return p.parse_args()


def apply_theme(theme):
    if theme == "dark":
        plt.style.use("dark_background")
        return {
            "bg": "#0a0e14", "panel": "#0f141c", "grid": "#22303c",
            "text": "#d7e2ea", "text_muted": "#7c8b96",
            "ok": "#3ddc84", "warn": "#f5c518", "crit": "#ff5c5c", "off": "#3a4550",
        }
    plt.style.use("default")
    return {
        "bg": "#f4f6f8", "panel": "#ffffff", "grid": "#c9d2d8",
        "text": "#1b232a", "text_muted": "#5a6570",
        "ok": "#2e9e5b", "warn": "#b8860b", "crit": "#c62828", "off": "#a9b3ba",
    }


def baro_altitude_m(pressure_hpa, qnh_hpa):
    """Standard ISA altitude (m) from pressure and reference QNH."""
    if pressure_hpa is None or pressure_hpa <= 0 or qnh_hpa is None or qnh_hpa <= 0:
        return float("nan")
    return 44330.77 * (1.0 - (pressure_hpa / qnh_hpa) ** 0.1902632)


class QuickView:
    def __init__(self, log_file, max_points, stale_after, theme, qnh, auto_qnh=True):
        self.log_file = log_file
        self.max_points = max_points if max_points > 0 else None
        self.stale_after = stale_after
        fallback_qnh = qnh if qnh is not None else DEFAULT_QNH_HPA
        self.qnh_provider = QnhProvider(
            fallback_qnh=fallback_qnh,
            enabled=auto_qnh,
        )
        self.qnh_provider.start()
        self.qnh = fallback_qnh
        self.palette = apply_theme(theme)
        self.file_pos = 0

        maker = (lambda: deque(maxlen=self.max_points)) if self.max_points else (lambda: deque())
        self.timestamps = defaultdict(maker)
        self.series = defaultdict(lambda: defaultdict(maker))
        self.last = {p: {} for p in PAYLOADS}
        self.last_seen_wall = {p: None for p in PAYLOADS}

        # cumulative sampled volume (L), continuous trapezoidal integration (never trimmed)
        self._volume_l = {p: 0.0 for p in PAYLOADS}
        self._last_flow = {p: None for p in PAYLOADS}
        self._last_flow_time = {p: None for p in PAYLOADS}

        # time anchor per payload: (gps_time_at_anchor, real_datetime_at_anchor)
        self._anchor = {p: None for p in PAYLOADS}

        self._build_figure()
        self.read_all_existing_lines()

    # ------------------------------------------------------------------
    # Figure and axes
    # ------------------------------------------------------------------
    def _build_figure(self):
        pal = self.palette
        self.fig = plt.figure(figsize=(19, 17.5), facecolor=pal["bg"])
        try:
            self.fig.canvas.manager.set_window_title("QuickView - vertical_sampler")
        except Exception:
            pass

        # 8 rows: original 6 + OPC-N3 heatmap + OPC-N3 scalars (kenttarova only)
        gs = gridspec.GridSpec(
            8, 1, figure=self.fig,
            height_ratios=[1, 1, 0.85, 1, 0.85, 1.05, 1.3, 1],
            hspace=0.32,
            left=0.075, right=0.965, top=0.955, bottom=0.055,
        )

        self.ax_batt = self.fig.add_subplot(gs[0])
        self.ax_temp = self.fig.add_subplot(gs[1], sharex=self.ax_batt)
        self.ax_press = self.fig.add_subplot(gs[2], sharex=self.ax_batt)
        self.ax_alt = self.fig.add_subplot(gs[3], sharex=self.ax_batt)
        self.ax_hum = self.fig.add_subplot(gs[4], sharex=self.ax_batt)
        self.ax_flow = self.fig.add_subplot(gs[5], sharex=self.ax_batt)
        self.ax_opc_heat = self.fig.add_subplot(gs[6], sharex=self.ax_batt)
        self.ax_opc_scalars = self.fig.add_subplot(gs[7], sharex=self.ax_batt)

        self.time_axes = [self.ax_batt, self.ax_temp, self.ax_press,
                           self.ax_alt, self.ax_hum, self.ax_flow,
                           self.ax_opc_heat, self.ax_opc_scalars]
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

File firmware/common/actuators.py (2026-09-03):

import digitalio
import config


def _set_output(output, value):
    if output.value != value:
        output.value = value


class Pump:
    def __init__(self, logger):
        self._front = digitalio.DigitalInOut(config.PUMP_FRONT)
        self._front.switch_to_output(value=False)
        self._back = digitalio.DigitalInOut(config.PUMP_BACK)
        self._back.switch_to_output(value=False)
        logger.info("Pump initialized: off")

    def set_state(self, location, state):
        if location not in ("front", "back", "both"):
            raise ValueError("pump location: front, back, or both")
        if state not in ("on", "off"):
            raise ValueError("pump state: on or off")
        value = state == "on"
        if location in ("front", "both"):
            _set_output(self._front, value)
        if location in ("back", "both"):
            _set_output(self._back, value)

    def front_state(self):
        return int(self._front.value)

    def back_state(self):
        return int(self._back.value)


class Valve:
    def __init__(self, logger):
        self._output = digitalio.DigitalInOut(config.ELECTROVALVE)
        self._output.switch_to_output(value=False)
        logger.info("Valve initialized: off")

    def set_state(self, state):
        if state not in ("on", "off"):
            raise ValueError("valve state: on or off")
        _set_output(self._output, state == "on")

    def state(self):
        return int(self._output.value)

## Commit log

2026-04-28 Initial commit: payload firmware, ground station, docs and Makefile
2026-06-09 docs: add "No space left on device" troubleshooting entry
2026-06-09 feat: pretty-print telemetry data as formatted table in cli.py
2026-06-09 fix: cli filters non-JSON lines; ground sends ACK prefix to avoid echo confusion
    [cli.py]
2026-06-09 fix: rewrite ground/main.py with synchronous request-response pattern (like original)
2026-06-09 fix: correct syntax error in ground/main.py (misplaced .encode() parentheses)
2026-06-09 feat: add ground/boot.py to enable usb_cdc data port; update Makefile
2026-06-09 fix: remove boot.py line from update-ground target
2026-06-09 fix: rewrite ground/main.py using sys.stdin (original working approach)
2026-06-09 fix: disable REPL echo in ground/main.py to prevent self-commands
2026-06-09 fix: remove debug kwarg from GPS, fix pump/valve response format, improve command listening window
    [payload.py]
2026-06-09 fix: battery monitor GP27, read actual flowmeter value from GP28
    [payload.py]
2026-06-15 fix: update FlowMeter.flow() formula for 10k/33k voltage divider and 4121 scale
    [payload.py]
2026-06-15 fix: correct flowmeter divider to 32.6k and add zero-flow offset calibration
    [payload.py]
2026-06-15 refactor: remove accidental common/ dir, move flowmeter fix into payload/payload.py
    [payload.py]
2026-06-15 chore: delete accidental common/ directory (led.py)
2026-06-15 chore: delete accidental common/ directory (pressure_sensor.py)
2026-06-15 Update flow offset calibration value
2026-06-16 fix: update payload.py and main.py files for new SDCard/logger API
    [payload.py]
2026-06-16 feat: add rtc_time to data JSON and sync RTC from GPS fix
    [payload.py]
2026-06-16 feat: add CPU temperature monitoring and battery low-voltage pump cutoff
2026-06-16 fix: calibrate battery voltage factor to 10.15 and remove debug print
    [payload.py]
2026-06-16 feat: watchdog timer and graceful SD failure handling
    [logging.py, payload.py, sdcard.py]
2026-06-16 docs: update README with current data format, SD logging, safety features and calibration
2026-06-17 payload: add automatic heartbeat every 60 s with per-unit offset
    - HEARTBEAT_INTERVAL_S = 60
    - HEARTBEAT_OFFSET_S per payload_id (matorova=0, kenttarova=30)
    to reduce LoRa collision probability
    - heartbeat is a normal data packet sent via lora.send() using the
    last collected data dict, so no new data structure is introduced
    - uses time.monotonic() for drift-free scheduling inside main_loop
    - existing command-listen window and all other behaviour unchanged
    [payload.py]
2026-06-17 cli: add 'monitor' subcommand with curses TUI
    - New top-level subcommand: monitor
    Usage: python cli.py monitor [--payloads matorova kenttarova] [--qnh 1013.25]
    - Two-column TUI (one per payload) with curses, auto-refreshing every
    POLL_INTERVAL_S (default 5 s) by polling 'data' on each payload
    - Pressure altitude computed from QNH and measured pressure (ISA formula)
    - Events pane: last 8 log lines at bottom
    - Key bindings: r=refresh now, 1/2=poll individual payload, q=quit
    - Falls back gracefully to plain-text output if curses unavailable
    - Existing pump / valve / data subcommands are completely unchanged
    - --log-file FILE: optional path to append JSONL records (one per poll)
    [cli.py]
2026-06-17 pack+cli: add cpu_temperature to binary pack; fix curses boundary ERR
    pack.py:
    - Add cpu_temperature (float 'f') as last field in KEYS/FORMAT
    - Binary format is now 15 fields; both payload and ground must be
    reflashed together (format is not backwards-compatible)
    cli.py:
    - Fix curses addnstr() ERR: clamp every write to cols-1 to avoid
    writing into the last column which raises ERR on many terminals
    - Remove cpu_temperature from N/A fallback — it is now in the pack
    [cli.py, pack.py]
2026-06-17 cli: fix monitor keyboard freeze — move serial poll to background thread
    Problem: _poll_payload() blocks up to 6 s waiting for a LoRa response.
    While it blocks, curses getch() never runs so q/r/1/2 are ignored.
    Fix:
    - PollWorker thread owns the serial port and a queue for results
    - Main curses loop only calls getch() and reads from the queue —
    never blocks on serial
    - Serial timeout lowered to 0.5 s for the monitor (fast turnaround)
    - find_serial() gains optional timeout_s parameter
    - All other subcommands (pump/valve/data) unchanged
    [cli.py]
2026-06-17 ground+cli: passive heartbeat listen; control keys in monitor; remove auto-poll
    ground/main.py:
    - Main loop now calls lora.receive(timeout=1) when no serial command
    is waiting, so heartbeats from payloads are forwarded to the host
    as JSON without needing an explicit 'data' poll
    - Command handling unchanged
    - Remove POLL_INTERVAL_S auto-poll from monitor (heartbeats arrive
    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
2026-06-18 pack+cli: add payload_id (10s) to binary pack so heartbeats are identifiable
    payload/pack.py:
    - Add ("payload_id", "10s") at end of KEYS
    - dict2bytes: encode string to fixed 10-byte field, zero-padded
    - bytes2dict: decode bytes field, strip null bytes and spaces
    - PollWorker._try_parse_heartbeat: match heartbeat to payload via
    payload_id field now present in every pack
    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
    [pack.py]
2026-06-18 pack: fix bytes padding for CircuitPython (no bytes.ljust)
    [pack.py]
2026-06-18 pack: fix bytes.decode for CircuitPython (no errors kwarg)
    [pack.py]
2026-07-09 Update safety check to include valve control
2026-07-09 payload: also close valve on critical temperature/battery in _check_safety
2026-07-09 ground: add --dump option and JSONL backup of decoded packets
2026-07-09 ground: revert local dump changes (keep ground station firmware untouched)
2026-07-09 tools: add quickview live plotting tool for ground JSONL logs
2026-07-09 tools: update quickview to stacked subplots sharing local time x-axis (use RTC/GPS time when available)
2026-07-09 Load entire JSONL history on startup
    - Add `read_all_existing_lines()` method to load all existing data when QuickView initializes
    - Call this method from `__init__()` to populate graphs with full historical data
    - Fixes issue where restarting QuickView would only show recent points instead of complete dataset
    - Maintains trailing window behavior (max_points still controls display limit) while ensuring no data is lost on restart
    [quickview.py]
2026-07-09 Fix duplicate initialization of _anchor variable
    [quickview.py]
2026-07-09 Remove RSSI subplot and actuator indicators from quickview.py
2026-07-09 Fix GridSpec rows and restore time formatting on bottom axis
    [quickview.py]
2026-07-10 Update RFM addresses for matorova, kenttarova, and ground
2026-07-13 Improve ground station telemetry robustness: drain old LoRa frames, filter by msg_type, handle null bytes
2026-07-14 fix(lora): persist cs and reset as instance attributes
    [lora.py]
2026-07-14 fix(payload): harden command parser against IndexError and send structured error
    [payload.py]
2026-07-14 fix(pack+cli): add msg_type field and filter by type when waiting for ACK
    payload/pack.py: prepend 8-byte msg_type to wire format; dict2bytes
    defaults missing msg_type to "telemetry" for backward compat during
    transition; bytes2dict exposes msg_type as string.
    cli.py: drain stale packets before sending a command; after sending,
    only accept msg_type==command_ack or command_error as a valid response,
    ignoring heartbeat/telemetry packets to avoid false ACK matches.
    [cli.py, pack.py]
2026-07-14 fix(payload): replace {**dict} spread with .copy() for CircuitPython compat
    [payload.py]
2026-07-14 fix(main): correct SDCard API call and init LoRa before SD on shared SPI
    - SDCard was called with kwarg fname= which does not exist in sdcard.py;
    payload_id was receiving "log.txt" instead of PAYLOAD_ID.
    - LoRa is now initialized before SDCard so the RFM9x reset+VERSION
    register read happens on a clean SPI bus, before the SD card
    can leave MISO in an undefined state on a mount error.
2026-07-14 fix(lora): use last_rssi cache instead of live SPI read in rssi()
    rfm9x.rssi is a @property that does a live SPI register read every time
    it is called. Between packets the value is stale anyway (it reflects the
    last received packet), and the extra SPI transaction contends with the SD
    card on the shared bus. adafruit_rfm9x already caches the value in
    self.last_rssi at receive() time, so use that instead. The public
    LoRa.rssi() signature is unchanged.
    [lora.py]
2026-07-14 fix(pack): widen msg_type field 8s->12s; export MSG_* constants
    "telemetry" is 9 chars and was silently truncated to "telemetr" by the
    "8s" struct format. This caused the msg_type filter in cli.py and
    ground/main.py to never match, so heartbeats leaked through as ACKs
    and command_ack packets were discarded.
    Fix: widen to "12s" (fits all current values with headroom: "telemetry"
    = 9, "cmd_ack" = 7, "cmd_err" = 7). _MSG_TYPE_LEN constant updated
    accordingly. Named constants MSG_TELEMETRY / MSG_COMMAND_ACK /
    MSG_COMMAND_ERROR were already present; no behaviour change except the
    field now round-trips correctly.
    Packet size increases by 4 bytes (58 -> 62 bytes). Both payload and
    ground must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
    [pack.py]
2026-07-14 fix(ground): sync msg_type strings and fix destination=None
    Two bugs fixed together because they both affect every command exchange:
    1. ground/main.py filtered for msg_type == "command_ack" but the payload
    sends "cmd_ack" (matching pack.MSG_COMMAND_ACK). The strings never
    matched, so the ground waited the full 20 s timeout on every command
    and fell through to the backward-compat branch that accepted any
    valid packet as an ACK. Fixed: use pack constants throughout.
    2. LoRa(destination=None) — if set_destination() was never called (e.g.
    a receive-only run or a bug in _process_command), rfm9x would try to
    build a RadioHead header with destination=None, which raises
    Ty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
2026-07-14 fix(pack): cast integer fields to int in dict2bytes
    CircuitPython's struct.pack raises "Can't convert float to int" when a
    value passed for an 'i' or 'L' format field is a Python float. This
    hit in production: gps_time is packed as 'L' but _collect_data assigns
    elapsed_time = time.time() - start_time
    which is always a float. The same silent risk exists for pump_front_state,
    pump_back_state, valve_state and rssi if they ever arrive as floats.
    Fix: explicitly cast non-None integer fields (format 'i', 'l', 'L', 'I')
    to int() before packing. No change to wire format or packet size.
    [pack.py]
2026-07-14 fix(payload): log cmd_ack send; guard empty data dict; shrink GPS timeout on command path
    Three coordinated fixes in payload.py:
    1. _handle_command now logs "cmd_ack sent" / "cmd_err sent" so failures
    are visible in Thonny. Previously _send_with_type() could raise and
    the exception was silently swallowed by the outer try/except which
    then called _send_with_type() again for cmd_err — potentially
    double-faulting.
    2. Guard empty data dict: if _handle_command is called before the first
    _collect_data() completes (data == {}), pack.dict2bytes fills every
    numeric field with fill values. That is correct behaviour, but add
    an explicit check and log so it is visible.
    3. GPS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
    [payload.py]
2026-07-14 fix: set PAYLOAD_ID to matorova and use it in logger name
    The hardcoded PAYLOAD_ID was "kenttarova" but this Pico is matorova.
    This caused the wire payload_id field to be "kenttarova", so the CLI
    monitor updated the kenttarova column instead of matorova, appearing
    as if no data was arriving.
    Also use PAYLOAD_ID in getLogger() so the Thonny log name matches
    the wire payload_id (was "payload-main", now "matorova-main").
2026-07-14 fix(pack): size-aware bytes2dict + log-friendly parse errors
    If the peer has an older pack.py without the msg_type field the wire
    packet will be (FORMAT_SIZE - 12) bytes. bytes2dict now detects this
    by checking len(b) against both struct sizes and falls back to the
    legacy format (no msg_type), tagging the result as MSG_TELEMETRY.
    This makes the ground work even if its pack.py predates msg_type,
    and it makes the payload tolerate old ground ACKs.
    Also expose WIRE_SIZE and LEGACY_SIZE as constants so callers can
    do a quick sanity check before calling bytes2dict.
    [pack.py]
2026-07-14 fix(ground): log parse errors and packet length for diagnostics
    _parse_packet was swallowing all exceptions silently, making it
    impossible to distinguish RF noise from a FORMAT mismatch.
    Now it prints a one-line diagnostic to stdout (visible in Thonny on
    the ground Pico) whenever a packet fails to parse, including the
    packet length and the exception message. Valid packets are unaffected.
    Also add WIRE_SIZE / LEGACY_SIZE pre-check: if pack exposes them,
    use them for a fast reject before calling bytes2dict.
2026-07-14 fix(cli): accept telemetry as valid response to 'data' command
    _read_cmd_response was filtering out msg_type=telemetry packets,
    which is exactly what the payload sends in reply to a 'data' command.
    This caused every 'data' request to time out with 'no response'.
    Fix: add an optional accept_telemetry flag (default False) so that
    relay_cmd and _poll_one pass True when the expected response IS a
    telemetry packet. All other callers (pump/valve) keep False and
    continue to wait for cmd_ack/cmd_err only.
    Also fix _MSG_TYPE_LEN constant: was 8 but msg_type field is 12 bytes.
    No functional impact today but avoids future confusion.
    [cli.py]
2026-07-14 fix(cli): replace deprecated utcfromtimestamp/utcnow with timezone-aware equivalents
    utcfromtimestamp() and utcnow() are deprecated since Python 3.12 and
    will be removed in a future version. Replace with:
    datetime.fromtimestamp(val, tz=datetime.timezone.utc)
    datetime.now(tz=datetime.timezone.utc)
    both of which produce timezone-aware UTC datetimes and suppress the
    DeprecationWarning. Output format is unchanged.
    [cli.py]
2026-07-14 fix(payload/lora): add reset_radio() for recovery after SPI glitches
    When the shared SPI bus glitches (e.g. loose connector under vibration)
    the RFM9x can enter an inconsistent state where it stops transmitting
    without raising an exception. Expose reset_radio() so the main loop can
    hardware-reset the module via the RESET pin before retrying, matching
    the SX1276 datasheet-recommended power-on-reset sequence (t_reset >= 100
    us, POR settling >= 5 ms). self.reset is already a persistent attribute
    so no extra pin allocation is needed.
    [lora.py]
2026-07-14 fix(payload/payload): reset LoRa after data-collection errors
    After a SPI glitch the RFM9x can silently stop transmitting while the
    payload keeps running. The previous code called _failed_reading_data()
    immediately, which called lora.send() on a potentially wedged module,
    producing corrupted packets (observed as 'unknown payload_id' on the
    ground) or total silence.
    Now we call lora.reset_radio() inside the except block before calling
    _failed_reading_data(), giving the module a chance to recover from the
    glitch. If reset_radio() itself raises, the inner except swallows it
    and behaviour falls back to the previous path — no regression possible.
    [payload.py]
2026-07-14 fix(payload/payload): discard garbage receive() output before command parsing
    After a SPI glitch the RFM9x can return spurious single-byte packets
    (e.g. 0x3D '=', register echoes) from its internal FIFO. These reach
    _handle_command(), fail every known-command check, and produce noisy
    'Unexpected command: =' warnings in the log.
    Add a cheap pre-filter at the top of _handle_command: require the raw
    bytes to be at least 4 bytes long AND decodeable to printable ASCII
    before attempting to parse. Anything shorter or non-printable is
    silently discarded with a DEBUG log. Valid commands ('pump front on',
    'valve off', 'data') are all longer than 4 bytes, so no legitimate
    command is ever dropped.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
    [payload.py]
2026-07-15 feat(cli): apply per-payload pressure offset calibration
    Adds _PRESSURE_OFFSET_HPA lookup and _apply_pressure_offset(), applied
    in PollWorker._enrich() before altitude calc. Raw pressure_sensor_pressure
    is preserved unmodified; corrected value stored separately as
    pressure_sensor_pressure_corrected. Offsets calibrated against TSI 4100
    reference (NIST-traceable).
    Low risk: purely additive, ground-side only, no firmware/protocol change.
    [cli.py]
2026-07-15 fix: apply pressure offset in relay_cmd (data subcommand)
    The `_apply_pressure_offset()` correction was only applied in the
    PollWorker._enrich() path (monitor TUI) but not in relay_cmd(), so
    `python cli.py data <payload>` was showing uncorrected raw pressure.
    Fix: apply offset and compute pressure altitude before pretty_print()
    in relay_cmd(), consistent with the monitor TUI behaviour.
    [cli.py]
2026-07-20 fix: gps_time field was using elapsed boot time instead of GPS UTC timestamp
    [payload.py]
2026-07-27 Enhance FlowMeter with oversampling and delay features
    Refactor FlowMeter to include oversampling and delay.
2026-07-29 Add Kicad PCB project
    [pcb.kicad_pcb, pcb.kicad_sch]
2026-07-29 New components layout
    [pcb.kicad_pcb, pcb.kicad_sch]
2026-07-29 new layout
    [pcb.kicad_pcb]
2026-07-30 v1 sent to JLCPCB
    [pcb.kicad_pcb, pcb.kicad_sch]
2026-08-18 refactor: map GPIO configuration to PCB v1
2026-08-18 refactor: integrate PCB v1 configuration
2026-08-18 refactor: use config.py for GPIO and constants in payload.py
    Remove hardcoded BOARD_GP_* pin assignments and local calibration /
    safety-limit / heartbeat constants from payload.py. Import config and
    reference config.* instead, matching the pattern already used by
    hardware.py.
    - I2C (RH sensor bus): config.I2C_SDA / config.I2C_SCL
    - GPS UART: config.GPS_UART_TX / config.GPS_UART_RX
    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
2026-08-18 refactor: fold address.py into config.py
    Add GROUND_RFM_ADDRESS, KENTTAROVA_RFM_ADDRESS, MATOROVA_RFM_ADDRESS to
    config.py so LoRa node addresses live alongside the rest of the hardware
    configuration. address.py is removed in a follow-up commit once all
    importers are updated.
2026-08-18 refactor: use config.py for LoRa addresses and SPI pins in ground/main.py
    Ground station was still wired to the old breadboard SPI pins
    (board.GP2/GP3/GP4) and imported address.py directly. Switch to
    config.SPI_SCK/MOSI/MISO (PCB v1 pin map) and config.*_RFM_ADDRESS,
    matching the payload side. No behavior changes beyond the pin update.
2026-08-18 refactor: remove address.py, superseded by config.py
    GROUND_RFM_ADDRESS / KENTTAROVA_RFM_ADDRESS / MATOROVA_RFM_ADDRESS now
    live in config.py. All importers (ground/main.py, payloads/kenttarova/main.py,
    payloads/matorova/main.py) were already updated.
2026-08-18 refactor: add led.py under firmware/common
2026-08-18 refactor: remove unused hardware.py prototype
    payload.py contains the active, hardware-validated drivers and the
    additional mission logic (RTC sync, watchdog, fast GPS, safety and LoRa
    recovery). hardware.py was an unintegrated duplicate prototype.
2026-08-31 Introduce minimal LoRa actuator payload core
2026-08-31 Add battery and CPU telemetry to payload core
2026-08-31 Add battery and CPU safety interlock
2026-08-31 Add shared-bus pressure sensor telemetry
2026-08-31 Add non-blocking payload LED status
2026-08-31 Add flowmeter and received RSSI telemetry
2026-09-01 Stabilize shared SPI SD card initialization
    [sdcard.py]
2026-09-01 Fix SD card CS pin initialization
    [sdcard.py]
2026-09-01 Simplify SD logging to single mount
2026-09-01 Refactor payload.py to enhance sensor integration
2026-09-01 Wire OPC-N3 into shared SPI bus, log full histogram to SD every 10s
2026-09-01 Send raw OPC-N3 histogram bins and status over LoRa, display in ground CLI
2026-09-01 Display OPC-N3 telemetry (temperature, humidity, flow, laser, bin total) in ground CLI
2026-09-01 Add OPC-N3 size-distribution heatmap and scalar panel to quickview
2026-09-01 Implement synthetic timestamp for GPS/RTC fallback
    Add synthetic timestamp generation for entries without GPS fix.
    [quickview.py]
2026-09-01 Verify OPC-N3 laser/fan power state after on(), retry on failure
    [opc_n3.py]
2026-09-03 Prevent duplicate actuator command retries
    Send pump and valve commands once and wait for an unambiguous acknowledgement. Ignore stale responses and avoid redundant GPIO writes so delayed command handling cannot re-enable a pump after it was switched off.
    [actuators.py, cli.py, ground_main.py]
2026-09-07 Serialize shared OPC/SD/LoRa SPI access and reduce SD logging
2026-09-07 Fix GP16/GP17 CS conflict by reusing SharedSPI CS objects
    [lora.py, opc_n3.py]
2026-09-07 Fix mid-transaction SD log, add write resilience and startup delay
    [config.py, kenttarova_main.py, matorova_main.py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]
2026-09-07 Enable OPC-N3 fan/laser warmup before first histogram read
2026-09-08 Fix 2-byte overflow for null opc_bin fields and heartbeat retry loop
    [pack.py, payload.py]
